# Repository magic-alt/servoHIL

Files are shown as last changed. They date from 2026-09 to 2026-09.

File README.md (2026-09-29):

# ServoHIL

**基于 Zynq UltraScale+ MPSoC 的单 SoC 实时伺服 Hardware-in-the-Loop 平台。**

ServoHIL 面向伺服驱动器、机器人关节模组与电机控制器的实时 HIL 验证。
当前活动硬件为 **Rev.B + ALINX AXU2CGB / ZU2CG**：ZU2CG 同时运行 Plant 与实时 I/O，
自研扩展板负责模拟量、PWM、编码器、RS-485、电源和独立硬件监督，不再增加第二颗 FPGA。

> **当前工程状态**
>
> - Schematic / source-level Layout entry：**已闭合**
> - PCB Layout：**允许开始**
> - Fabrication：**未放行**
> - Product / release qualification：**未放行**
>
> 机器契约：`layout_allowed=true`、`fabrication_allowed=false`、`release_allowed=false`。

---

## 1. Rev.B HIL 板架构

```text
                         ┌─────────────────────────────────────────────┐
                         │          ALINX AXU2CGB / ZU2CG            │
                         │                                             │
 Host / Test Software ──►│  PS/Linux        PL Real-Time Fabric       │
                         │                  ┌───────────────────────┐  │
                         │                  │ PMSM / mechanics Plant│  │
                         │                  │ stimulus / capture    │  │
                         │                  │ protocol engines      │  │
                         │                  │ health / lease logic  │  │
                         │                  └───────────┬───────────┘  │
                         └──────────────────────────────┼──────────────┘
                                                        │
                              J12 / 1.8 V                │ J15 / 3.3 V
                DAC + ADC high-speed digital             │ PWM / encoder / RS485 /
                                                        │ AUX / safety handshake
                                                        ▼
┌───────────────────────────────────────────────────────────────────────────────┐
│                         ServoHIL Rev.B Expansion Board                        │
│                                                                               │
│  9–15 V SELV                                                                 │
│      │                                                                        │
│      ▼                                                                        │
│  Fuse / reverse / TVS / TPS259474L eFuse                                     │
│      │                                                                        │
│      ├──► AP63201 ─► 6V2_PRE ─► LT3045 ─► +5V0_DAC                          │
│      │                         └► LT3045 ─► +5V2_PVDD                         │
│      ├──► AP63201 ─► 3V3_D                                                   │
│      ├──► AP63201 ─► 1V8_D                                                   │
│      └──► LT8330 ─► -6V2_PRE ─► LT3094 ─► -5V2_PVSS                         │
│                                  ADR4525 ─► VREF_2V5                          │
│                                                                               │
│  Analog Output                                                               │
│  ZU2CG ─► 4 × AD3542R ─► 8 × AO ─► 2 × ADG5412F ─► J5 ─► DUT              │
│                                                                               │
│  Analog Input                                                                │
│  DUT ─► J801 ─► protection + RC ─► AD7606C-16 ─► 8-lane serial ─► ZU2CG   │
│                                                                               │
│  Digital / Encoder                                                           │
│  DUT PWM ─► protection/buffer ───────────────────────────────────► ZU2CG     │
│  SSI/BiSS ⇄ THVD1450 PHY ⇄───────────────────────────────────────► ZU2CG     │
│  RS-485  ⇄ THVD1450 PHY ⇄───────────────────────────────────────► ZU2CG     │
│                                                                               │
│  Independent Supervision                                                     │
│  rail monitors + progress-qualified heartbeat + TPS3430 watchdog             │
│                  │                                                            │
│                  ├──► DAC reset / AO disconnect                              │
│                  ├──► HIL_FAULT_N / re-arm                                   │
│                  └──► AQY212GS floating DUT permit                           │
└───────────────────────────────────────────────────────────────────────────────┘
```

Rev.B 的核心目标不是做一块通用 DAQ，而是把
**`Plant → deterministic I/O → DUT → measurement → Plant`**
闭环所需的实时模拟/数字接口收敛到一块 ZU2CG 扩展板上，并对失效状态采用
fail-closed 的硬件边界。

---

## 2. 主要 I/O 能力

| 功能 | Rev.B 实现 | 备注 |
|---|---|---|
| Analog Output | 8 路，4 × AD3542RBCPZ16 | 16-bit DAC；经 ADG5412F 实现物理高阻断开 |
| Analog Input | 8 路，AD7606C-16BSTZ | 低能量实验室 ±10 V 前端候选；8-lane serial |
| PWM Capture | 6 路 | 3.3 V logic，SN74LVC541A 缓冲 |
| Encoder | 2 端口 SSI/BiSS-C | 每端口 CLK/DATA 两个差分对，THVD1450 |
| RS-485 | 1 路 | THVD1450，120 Ω 跳线终端 |
| AUX GPIO | 6 路 | 3.3 V logic |
| Management | I²C | 3.3 V |
| HIL handshake | HIL_ARM / HIL_WDI / HIL_FAULT_N | 与独立硬件 watchdog/supervision 配合 |
| DUT permit | 1 路 floating NO contact | AQY212GS；实验室非安全许可触点 |

当前扩展板**没有**板载 EtherCAT/CAN 控制器或 PHY；工业总线主站/协议验证属于其他
host/平台工作流，不应把 AUX 引脚描述成已实现 EtherCAT/CAN。

---

## 3. AXU2CGB / ZU2CG 接口

Rev.B 直接使用 AXU2CGB 的 J12/J15 扩展接口。

### J12 — 1.8 V GPIO domain

主要承载高速 ADC/DAC 数字接口：

- DAC：`SCLK`、`LDAC_N`、4 × `CS_N`、8 × `SDIO`、4 × `ALERT_N`
- ADC：8 × `DOUT`、`SCLK`、`CS_N`、`SDI`、`CONVST`、`BUSY`、`RESET`

### J15 — 3.3 V GPIO domain

主要承载外部数字/PHY 与硬件监督：

- 6 × PWM
- 2 × SSI/BiSS encoder ports
- 6 × AUX GPIO
- RS-485 TX/RX/DE
- I²C
- `HIL_ARM` / `HIL_WDI` / `HIL_FAULT_N`

完整逻辑映射见：

- `hardware/carriers/axu2cgb/physical_pinout.csv`
- `hardware/carriers/axu2cgb/assignments.csv`
- `hardware/revB/io_contract.json`

官方 ALINX DXF 已绑定：

- AXU2CGB outline：**100 × 85 mm**
- 4 个主安装孔及孔径
- J12/J15 2×20 / 2.54 mm pin grid
- J12/J15 几何中心
- 两个连接器的 pin-1 方向

仍未冻结：**AXU2CGB host connector MPN、mating connector MPN、mated stack height 和
carrier height keepout**。因此在这些机械事实闭合前，不使用通用 2×20 footprint
伪造可制造的 mating PCB。

---

## 4. 电源与模拟架构

Rev.B 接受 **9–15 V regulated SELV**，不是电机 48/67 V DC bus 输入。

### 输入保护

```text
J101
  │
  ▼
F101 2 A
  │
SS34 reverse-polarity protection
  │
SMBJ16A TVS
  │
TPS259474L eFuse
  │
VIN_PROT
```

关键设计计算：

- eFuse current limit：约 **1.51 A**
- UV：约 **7.95 V**
- OV：约 **15.91 V**

### 正电源

三路 AP63201：

| Rail | Nominal |
|---|---:|
| `6V2_PRE` | 6.184 V |
| `3V3_D` | 3.296 V |
| `1V8_D` | 1.792 V |

`6V2_PRE` 再经两路 LT3045 生成：

- `+5V0_DAC`
- `+5V2_PVDD`

### 负电源与参考

- LT8330 Cuk/inverting preregulator：约 `-6.24 V`
- LT3094：`-5V2_PVSS`
- ADR4525：`VREF_2V5`

当前 EDV 仍保留 DAC supply-span/headroom corner 问题；Layout 可以继续，
但 rail tolerance、DAC stability、MLCC derating、磁性损耗和实板 thermal
仍属于 fabrication/release gate。

详细计算：

- `docs/design/native-power-stage-calculations.md`
- `docs/design/native-power-supervision.md`
- `sim/power/README.md`

---

## 5. 硬件监督与失效语义

Rev.B 的 safety/interlock 设计原则是：

**软件/RTL 停止正常推进时，硬件必须能够独立撤销输出许可。**

主要链路包括：

- TPS3808 rail supervisors
- negative-rail comparator
- explicit arm / re-arm latch
- progress-qualified `HIL_WDI`
- TPS3430 window watchdog
- DAC hardware reset
- 2 × ADG5412F AO disconnect
- AQY212GS floating normally-open DUT permit

`health_heartbeat.sv` 不使用无条件 free-running heartbeat。
只有 Plant/I/O 完成序号持续推进并且 host lease 有效时才继续输出 WDI；
progress timeout、lease expiry、序号异常或显式 fault 都会撤销健康状态。

### 安全边界

以下语义必须保持明确：

- **AO disconnect = high impedance，不等于 guaranteed 0 V。**
- **J701 floating DUT permit 不是 STO。**
- J501/J701 为两线 contact 语义，跨线短路可能等效于“触点闭合”，因此
  **不是 cable-short fail-safe 或 redundant functional-safety channel**。
- Rev.B 当前定位为工程/实验室 HIL，不声明 IEC 功能安全认证。

---

## 6. 当前 Rev.B 工程状态

### 已完成

- 15 页原生 KiCad schematic topology
- 439 个 on-board physical instances
- 431 populated + 8 DNP
- native on-board blank footprint：**0**
- U20–U23 AD3542R exact CP-28-15 land pattern
- J101 / SW101 / J5 / J501 / J701 board-side exact part/footprint binding
- C105 TDK exact land pattern
- AD7606C-16 schematic + RTL initialization / eight-DOUT capture path
- PWM / SSI-BiSS / RS-485 / AUX electrical boundaries
- input/output connector protection topology
- progress-qualified heartbeat / watchdog integration framework
- source-bound electrical calculations and ngspice regression
- AXU2CGB official DXF mechanical baseline
- Rev.B complete costed BOM
- Layout-entry machine contract

### 当前 gate

| Gate | State |
|---|---|
| Schematic source closure | ✅ closed |
| Layout entry | ✅ `READY_FOR_PCB_LAYOUT` |
| PCB Layout | 🟡 active / next engineering phase |
| Fabrication | ❌ blocked |
| Product release | ❌ blocked |

机器状态源：

`hardware/revB/gates.json`

当前明确：

```text
layout_allowed      = true
fabrication_allowed = false
release_allowed     = false
```

---

## 7. PCB Layout 基线

Rev.B 目标为 **6-layer PCB**：

| Layer | Role |
|---|---|
| L1 | components + signals |
| L2 | continuous GND reference |
| L3 | power distribution + slow signals |
| L4 | signals |
| L5 | continuous GND reference |
| L6 | components + signals |

设计原则：

- 不硬切 AGND/DGND；使用连续 reference planes + functional zoning
- switcher hot loop 与 ADC/DAC/reference 空间隔离
- 高速/精密信号不得跨 reference-plane void
- 每次高速换层附近设置 GND stitching via
- ESD/TVS 紧邻 connector，回流路径最短
- ADC/DAC digital bus 保持短、少 stub、少 layer transition
- 120 Ω differential 目前是目标阻抗，不在厂商 stackup 前冻结 width/gap

Layout 顺序：

```text
mechanical reference / board outline / connector keepout
    ↓
stackup + design rules
    ↓
power + precision analog placement
    ↓
ground / return-path review
    ↓
routing
    ↓
PCB DRC
```

详细 contract：

- `hardware/revB/pcb_layout_contract.json`
- `hardware/revB/pcb_design_rules.json`
- `docs/review/revb-layout/README.md`

---

## 8. 完整 BOM 与当前成本

Rev.B costed BOM 由原生 KiCad 反向审计，不再依赖手工简化表。

`bom/revb-costed.csv`：

- **439** 个 on-board physical refs
- **431** populated
- **8** DNP
- **139** grouped procurement lines

2026-09-29 engineering planning snapshot：

| Build | Component cost |
|---|---:|
| 1 × fully populated Rev.B | **约 ¥4,085.41** |
| 5 × fully populated Rev.B | **约 ¥17,153.21** |
| 5-board average | **约 ¥3,430.64 / board** |

以上不含：

- bare PCB
- stencil
- SMT/THT assembly
- freight / VAT / duties
- AXU2CGB
- J12/J15 mating connector stack
- rework / yield reserve

4 × AD3542R 是主要成本来源；与 AD7606C-16 合计约占单板元器件预算的
**68%** 左右，因此首板更适合采用“多做裸板、少量全贴”的 staged population。

采购状态区分：

- `EXACT_QUOTE`
- `EXACT_MPN_NO_LIVE_QUOTE`
- `CANDIDATE_QUOTE`
- `ORDERABLE_MPN_MISMATCH`
- `BUDGET_GENERIC`
- `DNP`

当前 U501 仍显式标记采购异常：
schematic 为 `TPS3430DRCR`，当前 active orderable candidate 为
`TPS3430WDRCR`；fabrication 前必须完成 variant/package/timing 审查并统一 schematic/BOM，
不能静默替换。

详细成本与采购策略：

- `bom/revb-costed.csv`
- `bom/revb-cost-summary.json`
- `bom/revb-pricing-sources.csv`
- `docs/design/revb-procurement-and-cost.md`

---

## 9. 设计文档入口

第一次接手 Rev.B，建议按以下顺序阅读：

1. **本 README** — 系统架构、工程状态和路线图
2. **`docs/design/revb-hardware-design-guide.md`** — 单一完整硬件设计说明书
3. **`hardware/carriers/axu2cgb/assignments.csv`** — ZU2CG ↔ Rev.B 信号映射
4. **`hardware/revB/io_contract.json`** — I/O 电气与逻辑契约
5. **`hardware/revB/pcb_layout_contract.json`** — PCB Layout 边界
6. **`docs/review/revb-layout/README.md`** — Layout placement/routing 规则
7. **`docs/review/revb-peripherals/README.md`** — ADC / PHY
8. **`docs/review/revb-safety/README.md`** — watchdog / interlock / DUT permit
9. **`sim/power/README.md`** — EDV / ngspice
10. **`docs/design/revb-procurement-and-cost.md`** — BOM / cost / sourcing

活动 KiCad 工程：

```text
hardware/kicad/revB/axu2cgb_expansion/servohil_io_revB.kicad_pro
```

原生 `.kicad_sch/.kicad_sym/.kicad_pro` 是设计源。
历史 review PDF、早期 XML 和 Rev.A snapshot 仅作为历史证据，不覆盖当前 native source。

---

## 10. Repository layout

```text
servoHIL/
├─ hardware/
│  ├─ kicad/revB/axu2cgb_expansion/   # active native Rev.B schematic / PCB source
│  ├─ revB/                            # machine-readable design/release contracts
│  └─ carriers/axu2cgb/               # carrier pinout / assignments / mechanics
├─ rtl/revb/                           # ADC / health / runtime integration RTL
├─ sim/
│  ├─ power/                           # analytical + ngspice EDV
│  └─ peripherals/                     # load / ADC frontend screening
├─ bom/                                # complete costed BOM + source ledger
├─ docs/design/                        # consolidated engineering design docs
├─ docs/review/                        # review checkpoints / evidence notes
├─ tests/                              # source / mutation / contract regressions
├─ tools/                              # repository / schematic / BOM / qualification checkers
└─ archive/revA/                       # superseded dual-FPGA historical design
```

---

## 11. 本地验证

推荐环境：

- Python 3.11+
- KiCad CLI
- ngspice
- Icarus Verilog

核心 source/contract 检查：

```sh
python tools/check_revb_schematic_closure.py
python tools/check_revb_prelayout_contract.py
python tools/check_revb_pcb_layout_contract.py
python tools/check_revb_costed_bom.py
python tools/revb_qualification.py
python -m unittest discover -s tests -v
```

原生 KiCad/ERC 路径：

```sh
mkdir -p build/native

kicad-cli sch export netlist \
  --format kicadxml \
  -o build/native/netlist.xml \
  hardware/kicad/revB/axu2cgb_expansion/servohil_io_revB.kicad_sch

python tools/check_native_readability.py \
  --normalize build/native/netlist.xml \
  --output build/native/canonical.xml

python tools/verify_native_all.py build/native/canonical.xml --stage supervision
python tools/check_revb_netlist.py \
  build/native/canonical.xml \
  hardware/kicad/revB/axu2cgb_expansion/expected_connections.json

python tools/check_native_safety.py build/native/canonical.xml

kicad-cli sch erc \
  --format json \
  --exit-code-violations \
  -o build/native/erc.json \
  hardware/kicad/revB/axu2cgb_expansion/servohil_io_revB.kicad_sch

python tools/check_revb_erc.py build/native/erc.json
```

CI 的 skipped 项只有在明确缺少对应 native tool/evidence 时才可接受；
**自动化通过不等于 electrical qualification 或 fabrication release。**

---

## 12. Pre-Layout 成本 / 架构决策

在冻结 DAC、电源和 precision-analog placement 之前，项目增加一个个人版成本决策门：

- 不再把 **8 路 AD3542R-16 全装**视为首板默认配置；
- 当前推荐 baseline 为 **4 路 fast AO，可扩展到 8 路**；
- 优先验证 AD3542R-12 是否已满足实际 DUT 分辨率；
- AD7606C-16 可在首个闭环样机中作为可选 DNP；
- 必须先实测 `PWM capture -> Plant -> AO settled -> DUT ADC sample` 的真实时序余量；
- 如果余量 >10 us，才值得进一步切换 DAC80504 / DAC81404 一类低成本 DAC；
- 如果余量 <2 us，则继续保留 AD3542R fast-precision 路线。

完整决策、替代器件、成本和实施收益见：

`docs/design/revb-prelayout-cost-feasibility-decision.md`

该决策不改变机器 gate：`layout_allowed=true` 仍表示可以继续机械/板框/规则工作；
但 **DAC / analog power / precision placement 不应冻结**，直到 fast-AO 数量、有效分辨率
和 DUT ADC timing margin 三项实测闭合。

---

## 13. 下一阶段

原理图已经不再是主要工作面。当前工程优先级是：

1. **绑定 J12/J15 exact host/mating connector、stack height 与 height keepout**
2. 创建活动 `.kicad_pcb`
3. 冻结 board outline / mounting holes / connector placement / keepout
4. 绑定 PCB 厂 6-layer stackup 和真实 impedance geometry
5. power / precision-analog critical placement
6. grounding / return path review
7. routing
8. PCB DRC
9. fabrication qualification
10. 首板 bring-up + thermal / backfeed / fault injection / EMC
11. Vivado functional I/O DRC + STA/CDC
12. DUT adapter qualification
13. FOC physical closed-loop HIL acceptance

仍然阻塞 fabrication/release 的主要证据包括：

- exact J12/J15 connector stack
- MLCC DC-bias / temperature / aging / ESR / RMS
- XAL L(I,T) / AC / core / winding loss / saturation
- real DUT thresholds / leakage / cable-fault / shutdown time
- partial-power / backfeed
- mounted-board thermal
- low-energy fault-injection fixture
- Vivado raw I/O DRC + functional STA/CDC
- EMC / power-down / physical fault injection
- FOC closed-loop acceptance

---

## 14. Release philosophy

ServoHIL Rev.B 使用显式、fail-closed 的工程门禁：

- footprint 正确 ≠ electrical qualification
- ERC / DRC 通过 ≠ fabrication approval
- ngspice PASS ≠ mounted-board thermal PASS
- watchdog/interlock 电路存在 ≠ certified functional safety
- catalog rating ≠ real DUT compatibility
- prototype works ≠ release qualification

**只有与准确 source revision、实际硬件、实际 DUT 和原始测试 evidence 绑定的结果，
才允许关闭对应 release gate。**

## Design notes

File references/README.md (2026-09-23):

# Design references

Use vendor-primary documents for electrical freeze decisions.

## ADI

- AD3542R: https://www.analog.com/en/products/ad3542r.html
- EVAL-AD3542R: https://www.analog.com/en/resources/evaluation-hardware-and-software/evaluation-boards-kits/eval-ad3542r.html
- ADR4525: https://www.analog.com/en/products/adr4525.html
- ADP5054: https://www.analog.com/en/products/adp5054.html
- ADM1186: https://www.analog.com/en/products/adm1186.html
- LT3045: https://www.analog.com/en/products/lt3045.html
- LT3094: https://www.analog.com/en/products/lt3094.html
- LTC7149: https://www.analog.com/en/products/ltc7149.html

## AMD / Xilinx

- AMD 7 Series overview: https://docs.amd.com/v/u/en-US/ds180_7Series_Overview
- Artix-7 family: https://www.amd.com/en/products/adaptive-socs-and-fpgas/fpga/artix-7.html

## ALINX

- AXU2CGB product: https://www.en.alinx.com/Product/SoC-Development-Boards/Zynq-UltraScale-plus-MPSoC/AXU2CGB.html

Retain local vendor documents only when redistribution permits. Otherwise record the canonical URL and document revision/date.

Before freezing any resistor, capacitor, compensation, feedback or FPGA package-pin value, check the current vendor document and record the review source in the schematic or design note.

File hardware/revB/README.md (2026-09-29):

# Rev.B hardware contract and release boundary

Rev.B is a **single-ZU2CG** HIL architecture. The active editable native KiCad source is:

```text
hardware/kicad/revB/axu2cgb_expansion/servohil_io_revB.kicad_pro
```

For the consolidated design rationale, calculations, pin definitions, Layout
rules, procurement policy and first-board bring-up procedure, use:

- `docs/design/revb-hardware-design-guide.md`
- `docs/design/revb-procurement-and-cost.md`
- `bom/revb-costed.csv`

## Current gate state

The 15-page source-level schematic and Layout-entry contract are closed sufficiently
to start PCB placement/routing:

- `layout_allowed=true`
- `fabrication_allowed=false`
- `release_allowed=false`
- layout-entry status: `READY_FOR_PCB_LAYOUT`

This means **Layout may proceed, but Gerber/fabrication/production release may not**.

The five previously open board-side mechanical parts are now source-bound for
Layout: J101=Phoenix 1757242, SW101=PTS645SM43SMTR92 LFS,
J5=Phoenix 1844294, J501=Phoenix 1844210 and J701=Molex 43045-0212.
C105 is bound to TDK C5750X7R1V476M230KC and U20..U23 retain the reviewed exact
AD3542R CP-28-15 land pattern. The current native source audit has **zero on-board
blank footprints**.

AXU2CGB official CAD now binds the 100 x 85 mm host outline, four mounting holes,
J12/J15 pin grids/centers and pin-1 orientation. Exact host/mating connector MPN,
mated stack height and carrier component-height keepouts remain open, so a guessed
generic 2x20 mating footprint must not be released.

## Qualification boundary

The following remain fabrication/release gates:

- exact J12/J15 host/mating connector stack definition;
- manufacturer MLCC and magnetic characterization;
- power margin and DAC analog stability;
- real DUT adapter neutral/permit thresholds, leakage, cable-fault behavior and
  maximum shutdown time;
- partial-power/backfeed and powered-off interface behavior;
- assembled-board thermal;
- low-energy fault-injection fixture;
- Vivado raw I/O DRC and functional STA/CDC bound to the exact part/top/XDC/source;
- EMC, power-down, physical fault injection and FOC closed-loop acceptance.

J501/J701 remain laboratory non-safety dry-contact/permit interfaces. A cross-line
cable short can mimic a closed contact; neither interface is STO or redundant
functional safety.

## Costed BOM contract

`bom/revb-costed.csv` covers all **439** on-board physical refs:
**431 populated + 8 DNP**, grouped into **139 purchasing lines**.
`tools/check_revb_costed_bom.py` fails if coverage drifts.

The 2026-09-29 planning snapshot is approximately **CNY 4,085.41** components for
one fully stuffed board and **CNY 17,153.21** components for five fully stuffed
boards after applicable small-quantity breaks. These figures exclude PCB,
assembly, freight/tax, AXU2CGB and the still-unbound J12/J15 mating connector stack.

The BOM also records U501 as an explicit `ORDERABLE_MPN_MISMATCH`: schematic
`TPS3430DRCR` versus TI's current active orderable `TPS3430WDRCR`. It must be
resolved by design review before fabrication, not silently substituted.

## Checks

```sh
python tools/check_revb_schematic_closure.py
python tools/check_revb_prelayout_contract.py
python tools/check_revb_pcb_layout_contract.py
python tools/check_revb_costed_bom.py
python tools/revb_qualification.py
```

Passing these source/contract checks is not a physical qualification or production
certificate.

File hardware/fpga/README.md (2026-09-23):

# Local I/O FPGA hardware contract

Candidate device: `XC7A35T-1FGG484I`.

The Local FPGA is a deterministic I/O engine, not the plant solver.

Responsibilities:

- HIL-Link endpoint,
- edge/event timestamping,
- frame CRC and FIFO,
- AD3542R serialization and LDAC scheduling,
- autonomous watchdog/safe-state generation,
- future ADC/DIO/encoder PHY glue.

The Rev.A FPGA source-of-truth is under `hardware/fpga/revA/`.

Concrete PACKAGE_PIN constraints must originate from Vivado I/O Planner and then be cross-checked against the KiCad schematic. No BGA ball assignment is to be invented in documentation first.

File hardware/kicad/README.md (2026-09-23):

# KiCad hardware development rules

The native Rev.A project lives in `hardware/kicad/revA/`.

Rev.A is currently in the **schematic phase**. The machine-readable layout authority is `hardware/kicad/revA/layout_gate.yaml`.

## Sheet ownership

- 01_POWER_ENTRY
- 02_ANALOG_POWER
- 03_DIGITAL_POWER
- 04_AXU_HIL_LINK
- 05_IO_FPGA
- 06_DAC_0_3
- 07_DAC_4_7

Future ADC/DIO/Encoder/CAN/RS485/FIU sheets remain deferred.

## Rules

- Do not guess regulator magnetics/compensation.
- Do not guess XC7A35T BGA balls directly in KiCad.
- Treat `docs/icd/j12-hil-link.csv` as the J12 mapping authority.
- Treat Vivado I/O Planner/XDC as the FPGA pin-placement authority.
- Treat KiCad ERC plus schematic review as mandatory before layout.
- Generated fabrication output is not source-of-truth.

## Before layout

All entries in `layout_gate.yaml` must pass in a reviewed commit. CI intentionally blocks premature PCB layout.

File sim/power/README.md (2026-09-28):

# Rev.B Electrical Design Verification

**Engineering screening, NOT layout or purchase approval.** Native KiCad remains
unchanged. In particular, the currently requested +/-5 V output and the +/-5.2 V
rail tolerance/headroom conflict are not fixed by a successful simulator job.

## Reproduce

Use Python 3.11+ and ngspice on PATH, in a clean checkout of the PR branch.
The CI records the actual simulator version and executable SHA256. Linux CI uses
ngspice-42 at the reviewed checkpoint; do not assume another simulator version
has identical solver behavior. For tests only, `NGSPICE` may name an executable.
The `spice.py` command resolves `ngspice` from PATH.

```sh
python -m unittest discover -s tests -p 'test_edv*.py' -v
python sim/power/analysis.py --output build/edv/analysis
python sim/power/qualification.py --output build/edv/components
python sim/power/capacitors.py --output build/edv/capacitors
python sim/power/spice.py --output build/edv/run-001
python sim/power/evidence.py build/edv/run-001 --expected-source-commit "$(git rev-parse HEAD)"
python sim/power/analysis.py --strict-design --output build/edv/analysis
```

The final command must currently exit **2**, because design blockers exist.
Other commands exiting zero mean the calculation/execution/integrity work ran;
they do not clear `hardware/revB/gates.json`. On PowerShell, inspect
`$LASTEXITCODE` after the strict command. Never run all commands under an
unconditional `|| true` that hides simulation failures.

Every executed SPICE run requires a **new output directory**. Existing output is
refused, including a previous successful run. Keep failed runs for diagnosis;
choose `run-002` instead of overwriting evidence. A failure leaves a `FAILED`
manifest with the completed case count and original logs. A process killed
without cleanup may leave `RUNNING`; neither status passes `evidence.py`.

For one-case debugging use `--case buck_6V2_PRE_8V`. This produces a valid
single-case execution, but intentionally fails the **full-matrix** integrity
gate. `--emit-only` creates portable `.cir` decks and prints `EMITTED_NOT_RUN`.

## What the models cover

| Layer | Current implementation | What it cannot establish |
|---|---|---|
| Analytical | Native R/L/C values; FB and SET corners; 162 Cuk sensitivity points; thermal envelopes; nine capacitor banks | Dynamic stability, actual temperature, lifetime/production qualification |
| Switched power network | 12 buck + 4 Cuk cases; input ramps, half-to-full **resistive** load steps, switching-disable discharge | AP63201/LT8330 compensation, IC soft-start, Burst Mode, short-circuit/current limit or hiccup |
| LDO envelope | Nine SET-current/RSET corners; native CSET and Cout; assumed gm, fast-start, dropout and current ceiling | LT3045/LT3094 loop stability, PSRR, noise, thermal shutdown, reverse current, real PG timing |
| Vendor preparation | Exact LT3045/LT3094/LT8330 `.asy`/`.SUBCKT` pin-order binding and deck/model hashes | No manufacturer macro-model simulation has been executed here |
| Physical bench | No new board measurements | No hardware PASS |

The power topologies are explicit hand-authored bench networks with native-value
binding, not an automatic SPICE export of every KiCad wire or parasitic. A
native topology change requires reviewing the bench network as well as rerunning
the digest/connection checks; the source hash alone cannot prove physical fidelity.

`startup_s` is the first 90% crossing in the **imposed stimulus**, not a guaranteed
IC startup or monotonic-settling specification. `shutdown_v` is measured at
99.9% of the finite simulation end time, not an acceptance of safe discharge.
Buck/Cuk shutdown removes gate drive while holding the bus; LDO shutdown ramps
the input down. These are different cases, not a common system power-off test.
No AC loop-gain/phase-margin sweep is claimed.

The switched clock uses finite rise/fall of `T/100` and width `D*T - edge` to
preserve its integrated duty. The original 1 ns edge gave D=0.7744167 rather than
0.773 on ngspice-42. The original 0.001 duty-error gate remains unchanged, and a
real-simulator half-max-timestep regression checks mean/peak convergence.

### Cuk model applicability

For the uncoupled-inductor approximation, check the valley of the **sum** of the
currents flowing through the diode/switch. An individual inductor current
reversing is not, by itself, the diode discontinuous-mode criterion. Ninety-nine
of the 162 current analytical sensitivity points fail the positive-sum valley
check. Their CCM arithmetic remains visible for diagnosis, **not as a guaranteed
peak/RMS bound**. Exact feedback limits include the LT8330 Rev D p3 negative-FBX
range, pin-bias current and line regulation; `assumptions.json` records the source.

All four imposed-duty Cuk cases are outside the 5% mean-output screen. Retain
those results: do not adjust duty merely to turn the report green. Actual
closed-loop regulation/current stress still needs the correct manufacturer
model and independent bench evidence, including light-load mode.

## Exact components and MLCC curves

`component_candidates.json` binds five magnetic references to catalog candidates:
L201/L301/L302 XAL5050-103MEC, L202 XAL5050-682MEC and L203 XAL5030-472MEC.
Catalog typical Isat at 30% inductance drop and catalog temperature-rise current
are not guaranteed current limits on this PCB. Close L(I,T), high-frequency core
and winding loss, startup/fault current, footprint/height and actual temperature
before freezing parts. Cuk candidate rows expose the invalid-CCM screening status.

`capacitor_candidates.json` is a **candidate** catalog, not a BOM edit:

| Native bank | Candidate | Recorded caveat |
|---|---|---|
| Six 2x22 uF banks | TDK C3225X7R1C226M250AC, 16 V X7R 1210 | Production catalog part is **+/-20%**, max height 2.8 mm; do not apply generic +/-10% tolerance |
| C414/C415 | TDK C3225X7R1E106K250AC, 10 uF 25 V X7R 1210 | Higher voltage rating is not proof of interchangeability; effective-capacitance target still open |
| C410 | TDK CGA6L2X7R1H105K160AA, 1 uF 50 V X7R 1210 | Production automotive AEC-Q200 candidate; DC-bias, RMS-current/ESR and effective-C qualification remain open |
| C105 | TDK C5750X7R1V476M230KC, 47 uF 35 V X7R 2220 | Production exact-MPN screening candidate; native C105 now binds X7R, but the generic KiCad 2220 footprint still requires TDK exact land-pattern/height review; >=22 uF effective at 15.05 V still requires hash-bound DC-bias data plus temperature/aging and RMS/ESR review |

Exact manufacturer source discovery is now also centralized in
`hardware/revB/component_evidence_sources.json`. The Coilcraft XAL50xx document
and exact TDK characterization-sheet URLs are recorded there, with status explicitly
kept as source-located/not-hash-imported. Do not convert those URLs or transcribed
catalog values into a curve PASS. Archive the actual reviewed source bytes and
SHA-256, record test/graph conditions, then import reviewer-controlled normalized
data without extrapolation.

Manufacturer source URLs, lifecycle check date and height are in the catalog.
Every reference's native capacitance, case and minimum voltage rating is checked.
Changing the second parallel capacitor cannot silently reuse a stale candidate.
The catalog-specific report takes precedence over `analysis.py`'s explicitly
named generic 10%-tolerance sensitivity. With the 20%-tolerance 22 uF candidate,
20 uF effective requires at least 68.91% bias retention under the assumed 15%
temperature and 3% aging losses. That is a **requirement**, not imported data.
The 3% aging and 50 mV voltage reserve are still engineering assumptions.

### Coilcraft XAL L-vs-current evidence import

XAL L-vs-current evidence uses the same fail-closed pattern as MLCC curves. The
checked-in report without a curve pack remains `BLOCKED_MISSING_CURVE`:

```sh
python sim/power/magnetics.py --output build/edv/magnetics
```

After an engineer obtains the reviewed Coilcraft source bytes, create one pack
per exact MPN (`XAL5050-103MEC.json`, `XAL5050-682MEC.json`,
`XAL5030-472MEC.json`) with:

- `schema: 1`, `manufacturer: "Coilcraft"`, exact `part_number`;
- `characteristic: "L_VS_CURRENT_REFERENCE"`;
- the reviewed HTTPS `source_url`, retrieval date, reviewer and normalization note;
- conditions including `temperature_c` and a nonempty `curve_basis`;
- an `original` file + SHA-256 and reviewer-normalized CSV + SHA-256.

The normalized CSV columns are exactly `current_a,inductance_uh`, begin at 0 A,
remain strictly increasing in current, and are never extrapolated.

```sh
python sim/power/magnetics.py \
  --curve-dir /path/to/reviewed-xal-packs \
  --output build/edv/magnetics-with-curves
```

Even a byte-valid exact-MPN curve can only produce
`SCREEN_ONLY_REFERENCE_CURVE`; Coilcraft L(I) graphs are treated as
typical/reference evidence. AC/core+winding loss, startup/short saturation and
mounted-board thermal evidence remain separate blockers.

No actual manufacturer curve CSV has been imported. To import reviewed evidence:

```sh
python sim/power/capacitors.py --curve-dir /path/to/reviewed-packs --output build/edv/capacitors-with-curves
```

For each MPN, provide `<MPN>.json` containing `schema: 1`, exact `part_number`,
HTTPS `source_url`, ISO `retrieved_on`, named `reviewer`, `normalization_note`,
and `conditions` with `temperature_c`, `ac_voltage_rms_v`, `frequency_hz`.
Both `original` and `normalized_csv` records must contain a relative `file` path
and the actual lowercase SHA256. Retain the original vendor export or source
snapshot and the reviewer-controlled normalized CSV together in the pack.
CSV columns are exactly `voltage_v,retention`; normalize to 1 at 0 V, retain
strictly increasing voltage and finite positive fractions <=1. No extrapolation.
The importer calculates from the **hashed CSV bytes**, never optional JSON
`points`. Traversal, escaping symlinks, wrong MPN, missing conditions and hash
mismatch are rejected. Test fixtures are explicitly SYNTHETIC and are not vendor
curves. Hash matching proves byte identity, not source authenticity. Reference
curves at one temperature do not establish simultaneous bias/temperature or
lifetime bounds, and even a successful screen stays `NOT_QUALIFIED`.

## Manufacturer LTspice workflow

Obtain the exact device symbol and matching readable library from an authorized
ADI/LTspice installation or official device page, subject to its license. Do not
commit or publish vendor IP in this repo or generic CI artifacts. For example:

```sh
python sim/power/vendor_ltspice.py --device LT3045 --rail 5v2 --symbol /vendor/LT3045.asy --model /vendor/LT3045.lib --output build/edv/vendor-lt3045
python sim/power/vendor_ltspice.py --device LT3094 --symbol /vendor/LT3094.asy --model /vendor/LT3094.lib --output build/edv/vendor-lt3094
python sim/power/vendor_ltspice.py --device LT8330 --symbol /vendor/LT8330.asy --model /vendor/LT8330.lib --output build/edv/vendor-lt8330
```

These paths are examples, not a claim that those files are installed. Pin order
comes from `SpiceOrder`, not package pin numbers. Missing/encrypted/incompatible
headers mean BLOCKED; use the official demo workflow rather than guessing pins.
Do not substitute LT3045-1 or AP63200 for LT3045 or AP63201.

After preparation, inspect model licensing, all `.include` dependencies, pin
mapping, convergence and the vendor model's supported behaviors. Run the clean
bench in the actual licensed LTspice environment, retaining tool/version,
model/dependency hashes, deck, raw measurements and all stepped conditions.
Verify output polarity and realistic startup, full load, release and shutdown.
Repeat with reviewed effective C/ESR/DCR and temperature/load corners. The
preparation report stays `PREPARED_NOT_RUN`; it is **not** a result importer.
AP63201 exact vendor-model availability/coverage remains open. The preparation
uses assumed diode/ESR/DCR and does not independently qualify those components.

## Evidence and release boundary

`evidence.py` requires all 25 current case IDs, a clean source identity, matching
source digest, 125 artifact hashes, native-bound deck hashes and raw-log/JSON
measurement/assessment consistency. It rejects stale source, subsets, duplicated
cases and incomplete output. This is integrity verification, not cryptographic
simulator attestation or a full waveform-physics validator. `--root` permits
verifying an archived run against its accompanying exact source snapshot; never
silently point an old report at new source.

GitHub PR workflows may execute a **merge-test SHA**, not the PR head SHA.
`source_commit.txt`, `source_tree.txt`, `source.zip`, `results.json` and the
integrity report record that distinction. Match native-source files before
reusing a KiCad netlist from another read-only CI job.

The closure sequence is: resolve DAC supply/headroom architecture; run correct
vendor closed-loop/mode models; archive real MLCC and magnetic curves; close
thermal and input-protection/backfeed stress; then independent hardware tests
and a separate layout-gate review. Do not expand ADC/PHY or start PCB layout
because Python tests or ngspice returned success. See
[review evidence and open findings](../../docs/review/revb-edv/README.md).

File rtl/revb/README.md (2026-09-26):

# Rev.B runtime health producer

`health_heartbeat.sv` is a synthesizable one-clock-domain core. It is not a board
bitstream, a Plant implementation, an AXI register file or a CDC bridge.

At **100 MHz**, default WDI falling edges are **5 ms** apart; each half-period is
2.5 ms. PLANT/IO deadlines are 100 us and host lease is 10 ms. These are explicit
engineering defaults, not proof that a particular Plant satisfies its deadlines.
Clock changes require re-deriving all parameters; never retain a 100 MHz parameter
set while using another clock. Cycle limits are integers >=2.

## Accepted transaction contract

All data/control inputs must be stable in `clk` domain. Assert reset asynchronously
if required and deassert synchronously upstream. A PS/AXI producer must transfer
sequence and valid atomically, with a proper CDC handshake if clocks differ.

`plant_valid/plant_seq` acknowledge a completed Plant step. `io_valid/io_seq`
acknowledge the completed required I/O set for a step, not merely a FIFO write,
DMA submission, DAC command request or timer interrupt. `lease_valid/lease_seq`
acknowledge a genuinely renewed host/session lease. An always-incrementing PL
counter is not an acceptable implementation of any of these sources.

The first sequence establishes the baseline. Subsequent accepted progress must
be exactly +1 modulo 2^32. An identical value is ignored and does not extend the
deadline; a jump/backward sequence faults. If a faster producer coalesces work,
place a reviewed per-accepted-transaction sequence adapter upstream; this core
does not treat arbitrary jumps as proof of progress.

A fault latches WDI at its present level and immediately withdraws `hil_arm` on
the detecting clock. There is no synthetic final falling edge. Later activity
cannot clear the fault. To start/recover, pulse `session_start` with ARM low and
runtime_fault absent; all three sources must then establish fresh progress. A
session-start during healthy tracking faults rather than refreshing deadlines.

`healthy` means *runtime sources fresh*, **not board RAILS_OK**. WDI runs while
disarmed so the external TPS3430/two-edge/TPS3808 chain can qualify. HIL_FAULT_N
is not a pre-arm heartbeat qualifier: the existing board asserts fault while
unarmed, and feeding that back would deadlock startup. `arm_request` must remain
low until the commissioning controller has allowed the hardware qualification
sequence; then issue a fresh rising edge. A premature attempt can be rejected by
the board ARM latch and requires explicit disarm/retry, not automatic toggling.
A future board integration must validate that sequence and monitor the actual
DUT permit/feedback. No RAILS_OK GPIO or host-health integration is invented here.

The core sees ARM low in a healthy session before permitting a rising edge.
ARM high through reset/recovery never arms. Dropping ARM disarms without stopping
an otherwise healthy heartbeat. The external safety chain remains authoritative;
this single-clock RTL is not redundant and does not establish STO/SIL/PL.

## Latched reason mask

| Bit | Meaning |
|---|---|
| 0 | Explicit runtime fault |
| 1 / 2 / 3 | Plant / I/O / lease deadline |
| 4 / 5 / 6 | Plant / I/O / lease sequence discontinuity |
| 7 | Invalid session start (live session, ARM high or runtime fault) |

Deadlines count clocks since the last accepted advance. Progress on the last
allowed clock refreshes the age; absent/duplicate input at that clock faults.
Faults take precedence over heartbeat toggles and ARM rises. Source counters and
latched failures cannot wrap to healthy after a long outage.

## Verification

`python -m unittest discover -s tests -p test_health_rtl.py -v` runs real Icarus
compilation and simulation. Small-cycle directed vectors cover missing/duplicate
progress, discontinuities, uint32 wrap, deadline boundaries, fault priority,
held-high ARM, deliberate recovery and healthy-disarmed feed. A second bench
runs default parameters for 11 ms at 100 MHz and checks the actual 5 ms falling
edge interval. Numerical simulation is not timing closure or hardware evidence.

Still required: reviewed PS/AXI/CDC session integration; actual Plant and I/O
completion producers; top-level/XDC binding; Vivado synthesis/STA/IO DRC; external
watchdog startup and fault injection; measured hardware disable/DUT reaction.

## AD7606C-16 digital initialization / acquisition core

`ad7606c16_controller.sv` implements only the reviewed digital transaction
boundary. After an explicit `start_init`, it pulses RESET, writes CONFIG
address 0x02 with 0x18 (eight DOUT lanes), issues a serial register-read command,
and requires the following DOUTA frame to read back 0x18 before `configured`
can assert. The all-zero readback frame returns the device to ADC mode.

A `sample_request` then produces CONVST, requires BUSY assertion and
deassertion within the configured timeout, clocks exactly 16 bits from all eight
DOUT lanes, and only then emits one-cycle `sample_valid` and increments
`sample_seq`. CONFIG mismatch or BUSY timeout is latched fail-closed until a
new explicit initialization.

The core follows the AD7606C-16 serial software-mode command framing, but it is
not a calibration, anti-alias, 1 MSPS, CDC, top-level pin or Vivado timing proof.
Those remain separate qualification gates.

## Runtime completion integration

`runtime_health_integration.sv` is the narrow accepted-event boundary feeding
`health_heartbeat`. It accepts only completed Plant sequence events, completed
ADC sample sequence events, and validated host-lease renewal sequence events.
Duplicate or gapped sequences retain the existing fail-closed health behavior.

AXI/CDC/top-level adapters are intentionally outside this module. They must
convert their domain-specific acknowledgements into one-cycle accepted events in
the reviewed health clock domain; merely submitting work is not evidence of
completion. This wrapper therefore closes the semantic wiring seam, not the
Vivado CDC/timing or software authentication qualification.

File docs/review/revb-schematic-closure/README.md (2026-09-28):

# Rev.B schematic closure

**Date:** 2026-09-28  
**Scope:** native KiCad source closure only; no PCB/Layout authorization.

## What is closed in source

The Rev.B root project contains **15 functional sheets** and 439 physical
`in_bom=yes && on_board=yes` instances by the source audit. Purchased AXU2CGB
J12/J15 interfaces are schematic boundaries, not expansion-board placements.

This closure includes:

- connector protection placed in the owning interface sheets (`03/06/50/70/80`) so page-local nets remain local;
- exact local package bindings where the reviewed manufacturer package has a matching
  project-local KiCad land pattern: LT3045/LT3094 MSOP-12+EP, TPS3430 DRC VSON,
  LVC1G74 DCT, AQY212GS SOP-4, Littelfuse 451 fuse, XAL5030 and the reviewed
  TPS259474 RPW/XAL5050 land-pattern bindings;
- exact AD3542RBCPZ16 CP-28-15 bindings on U20..U23 using a locally vendored
  footprint reconstructed and independently checked against the official
  EVAL-AD3542RFMCZ IPC-356/top-copper/solder-mask/paste evidence;
- a fail-closed package/BOM audit in `tools/check_revb_schematic_closure.py`;
- connector-side clamps for low-energy AI/AO, 3.3 V logic, SSI/BiSS, RS-485 and the
  dry-contact interlock;
- independent oracle assertions for the added protection-device pins and packages.

## Deliberate remaining physical bindings

The only blank physical footprints allowed are defined in
`hardware/revB/schematic_open_items.json`. At this checkpoint there are **5**,
all requiring the real mechanical/enclosure/cable/DUT contract:

- J101 — 12 V field connector;
- SW101 — power-reset switch;
- J5 — AO connector;
- J501 — 3.3 V dry-contact service connector;
- J701 — floating DUT-permit connector.

U20..U23 are no longer blank-footprint blockers. The AD3542R package review is
source-bound through:

- `hardware/revB/ad3542r_footprint_evidence.json`;
- `hardware/revB/evidence/ad3542r/u1_geometry_review.json`;
- `Package_DFN_QFN:AnalogDevices_CP-28-15_AD3542R`.

The official EVAL BOM binds U1 to AD3542RBCPZ16. The official IPC-356 contains
exactly pins 1..28, and the EVAL top copper/paste/mask data defines a 28-pad
perimeter land pattern at 0.40 mm pitch with **no center exposed pad**. The local
footprint reproduces those copper/paste dimensions and explicit mask apertures.
A generic nominal 4 mm QFN is still not an acceptable substitute.

U101 and L201/L202/L301/L302 are likewise no longer blank-footprint blockers.
Their package/land-pattern bindings are source-closed, but that **does not**
qualify the components electrically, thermally or mechanically for production.

L203 uses the exact official `Inductor_SMD:L_Coilcraft_XAL5030` footprint.
None of these footprint assignments establish L(I,T), AC/core loss, startup
saturation, board temperature rise, placement clearance or manufacturability.

## AD3542R package evidence boundary

The AD3542R package blocker is now closed at source level, not by package-name
guessing. The review pins the exact manufacturer artifact SHA-256 values and retains
the U1 IPC-356/Gerber geometry needed to reproduce the footprint.

This closure proves the checked-in U20..U23 land-pattern binding. It does **not**
qualify DAC accuracy, dynamic settling, output stability, thermal behavior, EMC,
fabrication process or the finished PCB.

## Protection boundary

The DUT-permit protection intentionally does not clamp the floating
`DUT_PERMIT_A/B` contact to board ground. Cross-line protection must be selected only
after the actual DUT voltage, leakage, cable and isolation requirements are bound.

All connector protection parts are source-level topology decisions. Physical
qualification still requires connector-entry placement review, short return paths,
partial-power/backfeed tests, cable/common-mode conditions, IEC ESD/surge testing and
raw evidence.

## Electrical qualification boundary

The XAL5050/XAL5030 candidate MPNs and their catalog Isat/Irms/DCR values are screening
inputs, not board qualification. The remaining magnetic gate requires, at minimum:

- supplier L-versus-DC-bias and temperature evidence;
- AC/core plus winding-loss evaluation at the actual switching waveforms;
- startup/short-circuit/current-limit saturation analysis;
- exact land-pattern/height/clearance verification;
- mounted-board temperature-rise evidence.

MLCC candidates similarly remain blocked on exact-MPN DC-bias evidence, aging,
temperature, RMS-current/ESR where applicable, and real load/startup transients.
Analytical EDV success must not be converted into a production PASS.

## Release boundary

`hardware/revB/gates.json:layout_allowed` remains `false`.
The following cannot be inferred from passing ERC, source audits or RTL simulation:

- real DUT neutral/permit thresholds, leakage, cable-fault response or shutdown time;
- board thermal, MLCC bias/aging and magnetic loss/saturation qualification;
- DAC stability/accuracy and ADC analog precision/sample-rate qualification;
- powered-off backfeed and cable transient behavior;
- Vivado STA/IO DRC until reports bound to the exact source/top/part/XDC are imported;
- EMC, fault injection or FOC closed-loop acceptance on physical hardware.

The next engineering step is therefore evidence/physical binding, not adding more
functional schematic pages.

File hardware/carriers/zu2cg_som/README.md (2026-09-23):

# ZU2CG SoM carrier binding (not selected)

This is an alternative to AXU2CGB, NOT another FPGA connected to it.

The common logical contract is `hardware/revB/io_contract.json`. A native physical
project/XDC cannot be generated while this profile is UNBOUND. To bind a module:

1. Select an exact vendor/module/hardware revision and archive its interface evidence.
2. Populate a separate `physical_pinout.csv` (connector,pin,board_signal,soc_ball,
   bank_group,voltage,kind,source), with no functional net names mixed in.
3. Populate `assignments.csv` (net,connector,pin) from the common contract.
4. Record the canonical CSV SHA256, vendor power/boot contract and FPGA device.
5. Set status to BOUND_CANDIDATE, not PASS. Run the same validator and native
   netlist/ERC checks. Binding does not close hardware validation gates.

The current generator accepts only physically matching common voltage domains.
A module with only 1.8V HP pins needs actual reviewed 3.3V translation/PHY changes;
the validator deliberately rejects voltage mismatch rather than silently aliasing
it. The fixed common I/O design is reusable; the carrier power, level conversion,
connector layout and exact balls are not vendor-independent.

A purchased module is responsible for SoC BGA, DDR, boot storage and internal
core supply. The carrier must supply only the vendor-required module input(s),
not a guessed copy of the removed local-FPGA power tree.

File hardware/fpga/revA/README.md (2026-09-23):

# Rev.A Local I/O FPGA pin planning

Candidate device: **XC7A35T-1FGG484I**.

Exact PACKAGE_PIN assignments are intentionally not guessed. Generate them in Vivado I/O Planner after bank voltage, clock-capable pin and escape requirements are reviewed.

| Function | VCCO | Requirement |
|---|---:|---|
| configuration/QSPI/debug | 3.3 V | compatible flash/JTAG |
| HIL-Link | 1.8 V | source-synchronous 100 MHz DDR; clock-capable input pin |
| AD3542R digital | 1.8 V | SCLK/CS/SDIO/LDAC/RESET |
| future I/O | TBD | reserved for Rev.B |

Before schematic freeze:
- fill real FGG484 balls in `pin_plan.csv`;
- generate `servohil_io_revA.xdc` with PACKAGE_PIN and IOSTANDARD;
- add HIL-Link timing constraints;
- cross-check schematic pins against XDC;
- pass Vivado DRC for bank voltage and clock placement.

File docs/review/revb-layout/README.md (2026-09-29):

# Rev.B PCB Layout — Phase 1

## Scope

PR #30 closed the **schematic/Layout-entry gate**. This phase therefore does not reopen the 15-page schematic architecture. The active sequence is:

1. carrier mechanical reference, board outline, mounting holes, connector placement and keepouts;
2. six-layer stackup and design rules;
3. power and precision-analog placement;
4. grounding and return-path control;
5. routing;
6. KiCad PCB DRC and layout review.

The source-of-truth contracts are:

- `hardware/revB/pcb_layout_contract.json`
- `hardware/revB/pcb_design_rules.json`
- `hardware/revB/layout_entry_contract.json`

`layout_allowed=true` remains independent from `fabrication_allowed=false` and
`release_allowed=false`.

## Mechanical baseline

The original AXU2CGB exposes J12 and J15 as two 40-pin, 0.1-inch / 2.54 mm
expansion ports. The repository already binds the logical pinout in
`hardware/carriers/axu2cgb/physical_pinout.csv` and the 64 used signals in
`assignments.csv`.

The schematic intentionally represents J12/J15 as **purchased-host logical
boundaries** with `on_board=no`. That was correct for schematic closure, but a
directly mated PCB requires a physical expansion-board mating connector and exact
mechanical registration.

The pinned manufacturer DXF now binds the 100 x 85 mm host outline, four primary
mounting holes, both 2x20 pin grids, J12/J15 geometric centers, and pin-1
orientation. Pin 1 is the non-circular square `PIN_TOP` pad: J12 is at
`(6.5278, 18.3769)` and J15 at `(93.4720, 66.6369)` in ALINX DXF native mm.

The remaining mechanical inputs that must be bound before a real mating
connector footprint / stack is released are:

- exact host connector manufacturer/MPN and expansion-board mating MPN;
- mated stack height;
- tall-component / heatsink / connector keepouts.

**Do not scale a product photograph into manufacturing coordinates.**

These remaining items are PCB mechanical inputs, not a reason to return to broad
schematic redesign. Until connector MPN/stack height is bound, PR #31 keeps the
native `.kicad_pcb` intentionally absent rather than committing a guessed generic
2x20 footprint. If direct mezzanine mating is selected, the only schematic
adjustment should be the minimum reviewed representation needed to give the
physical mating connectors real nets/ratsnest connectivity.

## Stackup target

Use a six-layer role stack while the manufacturer-specific dielectric geometry is
still unbound:

| Layer | Role |
|---|---|
| L1 / F.Cu | components + signals |
| L2 / In1.Cu | continuous GND reference |
| L3 / In2.Cu | power distribution + slow signals |
| L4 / In3.Cu | signals |
| L5 / In4.Cu | continuous GND reference |
| L6 / B.Cu | components + signals |

Nominal total thickness is 1.6 mm only as a mechanical target. Copper thickness,
dielectric thickness, finished impedance geometry and via capability must be
rebound to the chosen PCB fabricator before fabrication release.

## Grounding / return path

The board uses **continuous reference planes with functional zoning**, not hard
AGND/DGND islands.

- Keep L2 and L5 continuous GND.
- Separate switchers, digital PHY, ADC and DAC by placement and current-loop
  geometry.
- Never route a fast or precision signal across a reference-plane void.
- Put a nearby GND stitching via next to each high-speed layer transition.
- Keep switching current return loops local.
- Put connector ESD return vias immediately beside the protection device.
- J5 pins 9/10 are signal GND, not chassis/PE.

## Placement order

### 1. Input power

Place in physical current-flow order:

`J101 -> F101 -> D101/D102 -> U101 -> C105`

Keep TVS/eFuse/bulk paths compact and reserve an edge-access zone for J101 and
SW101.

### 2. Switching power

Treat each converter as a compact island:

- U201/L201 — 6V2_PRE
- U202/L202 — 3V3_D
- U203/L203 — 1V8_D
- U301/L301/L302/D301/C410/C411 — negative preregulator

The SW-node copper is intentionally small. Do not route it under or adjacent to
ADC, DAC, reference or low-noise LDO networks.

### 3. Low-noise rails and precision analog

Place U211/U212/U302 downstream of the switching stages and close to their
precision loads. Cluster U20-U23 with local decoupling/output networks. Orient
the DAC region so digital traffic enters from the host side and AO paths leave
toward J5.

For U801, keep reference/REGCAP/decoupling and the input RC network compact.
Connector-side protection is physically before the ADC victim.

### 4. External PHY

For encoder/RS-485 paths, use:

`external connector -> protection -> termination/transceiver -> digital logic`

Keep the A/B pair coupled and free of long stubs. A 120-ohm differential target
is a **target**, not a released width/gap, until the board shop stackup is
selected.

## Baseline geometry

The current layout target is intentionally conservative for prototype-capable
fabrication:

- default clearance: 0.20 mm;
- default signal width: 0.20 mm;
- default via: 0.60 / 0.30 mm;
- copper-to-edge: 0.30 mm;
- VIN_RAW/VIN_PROT: polygon or >=1.00 mm trace when not poured;
- medium-current rails: polygon or >=0.50 mm trace when not poured.

These dimensions are Layout defaults, not a manufacturer process approval.

## Routing priority

1. switching hot loops and power current paths;
2. precision reference / DAC / ADC analog;
3. external differential pairs;
4. fast DAC/ADC digital groups;
5. safety handshake/control;
6. remaining low-speed signals.

The fast J12 ADC/DAC buses must remain compact over an uninterrupted GND
reference, with no long stubs and few vias. Numeric skew limits are not invented
here; they are closed later with the functional timing contract.

## PCB DRC close criteria

Layout close requires:

- zero unconnected items;
- zero clearance, width, via and board-edge violations;
- all courtyard overlaps reviewed and no unwaived conflict;
- connector keepouts and access envelopes reviewed;
- a selected-fabricator stackup before controlled-impedance geometry is treated
  as closed.

Passing PCB DRC does **not** authorize Gerber/fabrication.

## Gates that remain outside Layout entry

The following remain fabrication/release gates and continue in parallel without
blocking placement/routing:

- manufacturer MLCC/magnetics curves;
- real DUT adapter thresholds/leakage/shutdown timing;
- partial-power/backfeed;
- assembled-board thermal;
- low-energy fixture/fault injection;
- Vivado raw I/O DRC and functional STA/CDC;
- EMC, power-down, fault injection and FOC closed-loop acceptance.

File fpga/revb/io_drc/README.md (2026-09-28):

# Rev.B AXU2CGB Vivado I/O DRC harness

This directory is a **constraint-validation harness**, not the functional ServoHIL FPGA top.

It exists to answer one narrow question before functional integration:

> Do the current Rev.B AXU2CGB package-pin and IOSTANDARD assignments load and pass strict Vivado I/O DRC for the bound device `xczu2cg-sfvc784-1-e`?

It deliberately does **not** claim functional timing, latency, CDC correctness, plant execution, ADC timing, PWM capture timing or a production bitstream.

## Inputs

- target part: `xczu2cg-sfvc784-1-e`
- top: `servohil_io_drc_top`
- port contract: `hardware/revB/io_contract.json`
- physical assignment provenance: `hardware/carriers/axu2cgb/profile.json` plus the native `carrier.xdc.preview`
- harness XDC: `axu2cgb_io_drc.xdc`

The harness XDC is only approved for this I/O-DRC scope. It contains package-pin and IOSTANDARD assignments only. It is not the future functional timing XDC.

## Run

From repository root with Vivado on PATH:

```sh
digest="$(python tools/revb_vivado_io_evidence.py source-digest)"
vivado -mode batch -source fpga/revb/io_drc/run_io_drc.tcl -tclargs build/revb-vivado-io-drc "$(git rev-parse HEAD)" "$digest"
```

PowerShell:

```powershell
$digest = python tools/revb_vivado_io_evidence.py source-digest
vivado -mode batch -source fpga/revb/io_drc/run_io_drc.tcl -tclargs build/revb-vivado-io-drc $(git rev-parse HEAD) $digest
```

Expected raw outputs:

- `report_drc.rpt`
- `report_io.rpt`
- `report_utilization.rpt`
- `io_drc_placed.dcp`
- `io_runtime.csv`
- `drc_summary.json`
- `run_identity.txt`

The Tcl exits non-zero when Vivado reports an Error or Critical Warning DRC violation.

## Evidence boundary

A successful local command is not yet a checked-in PASS. The raw reports must be imported through the Rev.B source-bound evidence envelope with:

- exact source commit/digest;
- exact target part and harness top;
- Vivado version;
- raw report path and SHA-256.

Functional STA remains blocked until a real functional top, clock/generated-clock definitions, I/O delays and timing/CDC policy are bound.

## Import source-bound raw evidence

After a successful Vivado run, validate the raw directory independently:

```sh
python tools/revb_vivado_io_evidence.py validate-run build/revb-vivado-io-drc
```

Then prepare a non-overwriting evidence pack under the repository top-level
`evidence/` directory:

```sh
python tools/revb_vivado_io_evidence.py prepare \
  build/revb-vivado-io-drc \
  evidence/revb/vivado_io_drc/<run-id> \
  --source-commit "$(git rev-parse HEAD)" \
  --reviewer "<reviewer>" \
  --reviewed-on YYYY-MM-DD
```

The prepared `evidence.json` may be registered as
`prelayout_evidence_status.json -> vivado -> VIVADO_IO_DRC` only after review.
The importer checks the Vivado runtime I/O table against all 64 expected pins and
I/O standards, requires zero Error/Critical Warning DRC findings, SHA-256 binds
every retained raw artifact, and rejects a raw run whose recorded source digest
does not exactly match the current repository source.

This still leaves `VIVADO_TIMING=NOT_RUN`.

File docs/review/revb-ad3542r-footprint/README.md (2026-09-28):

# AD3542RBCPZ16 / CP-28-15 footprint evidence review

**Date:** 2026-09-28  
**Scope:** U20..U23 exact land-pattern closure for Rev.B.  
**Result:** **RESOLVED IN SOURCE — official EVAL Gerber/BOM and current package documentation reviewed; Layout remains blocked.**

## Exact device and package identity

The active DAC is **Analog Devices AD3542RBCPZ16**. Current Rev.C documentation
identifies package option **CP-28-15**, a 28-lead LFCSP with a 4 mm × 4 mm body,
0.95 mm nominal height and 0.40 mm pitch.

Manufacturer sources remain:

- product/CAD entry:
  https://www.analog.com/en/products/AD3542R.html
- Rev.C data sheet:
  https://www.analog.com/media/en/technical-documentation/data-sheets/ad3542r.pdf
- CP-28-15 package drawing:
  https://www.analog.com/media/en/package-pcb-resources/package/pkg_pdf/lfcspcp/cp-28/cp-28-15.pdf
- EVAL-AD3542RFMCZ Gerber:
  https://wiki.analog.com/_media/resources/eval/user-guides/dac/eval-ad3542r/09-050892-01c.zip
- EVAL-AD3542RFMCZ BOM:
  https://wiki.analog.com/_media/resources/eval/user-guides/dac/eval-ad3542r/05-050892-01-d.xlsx

The official EVAL files are also discoverable through the Analog Devices public
documentation repository at
`analogdevicesinc/system-level@76eb29d83e6eaca9ce4470921d315938b2b1aa17`.

## Source artifacts reviewed

The review pins the exact downloaded artifacts by SHA-256 rather than redistributing
manufacturer binary files:

| Artifact | SHA-256 |
| --- | --- |
| `ad3542r.pdf` Rev.C | `a9536b981e1dc140082ddff947487faaaa47874cd8b648966ee9c6b92fa292fa` |
| `cp-28-15.pdf` | `f6aab2aa746e79a01b4d9067bde56c886001a4cb1b7ed83e198d480ab0845b73` |
| `eval-ad3542r-ug-2258.pdf` | `ed5afa177bce6c907a3981c71f49cc3964078a6b6ff79ecfd24ae78f6a1093b4` |
| `09-050892-01c.zip` | `87eee7f3ed85e81798918b1977bc0b416d72699a39c771d95e9ea3839ef461e8` |
| `05-050892-01-d.xlsx` | `4608d8884754e5768424832af2331fa0490ab90e05a990a1292bf8f7bab0f7df` |

The deterministic review record is:

`hardware/revB/evidence/ad3542r/u1_geometry_review.json`

It retains source/member hashes, all 28 U1 IPC-356 records, the exact Gerber U1
flash coordinates/apertures, the EVAL BOM U1 identity and the canonical KiCad pad
mapping.

## Official EVAL U1 identity

The EVAL BOM binds:

- reference: **U1**
- manufacturer: **ANALOG DEVICES**
- manufacturer part: **AD3542RBCPZ16**
- JEDEC field: **QFN28_4X4**

The IPC-356 file contains exactly U1 terminals **1 through 28**, with 0.40 mm pitch.
There is no U1 terminal 29 or exposed-pad terminal.

## Exact reviewed land pattern

The EVAL U1 pad-center offset from package center is **1.8933 mm**.

Official Gerber apertures are:

| Layer | Side pads | Top/bottom pads |
| --- | --- | --- |
| Top copper `L1_TOP.art` | 0.7366 × 0.2286 mm obround | 0.2286 × 0.7366 mm obround |
| Top paste `PMT.art` | 0.7366 × 0.2286 mm obround | 0.2286 × 0.7366 mm obround |
| Top solder mask `SMT.art` | 0.8382 × 0.2794 mm obround | 0.2794 × 0.8382 mm obround |

All three layers resolve exactly 28 perimeter positions for U1.

The local source footprint is:

`Package_DFN_QFN:AnalogDevices_CP-28-15_AD3542R`

at:

`hardware/kicad/revB/axu2cgb_expansion/footprints/Package_DFN_QFN.pretty/AnalogDevices_CP-28-15_AD3542R.kicad_mod`

Numbered pads reproduce the official EVAL copper/paste dimensions. Independent,
unnumbered F.Mask aperture pads reproduce the asymmetric official solder-mask
openings rather than approximating them with one isotropic mask expansion.

## Center/exposed-pad decision

The earlier preliminary-document ambiguity is now resolved for the current
manufacturing decision.

The following current evidence agrees:

1. Rev.C pin configuration enumerates pins 1..28 without an exposed-pad terminal.
2. CP-28-15 bottom view shows 28 perimeter terminals and no center pad.
3. EVAL IPC-356 contains exactly U1 pins 1..28.
4. EVAL top solder-mask and paste files contain 28 perimeter apertures and no center
   aperture.

Therefore the reviewed footprint **must not add a center/exposed pad**.

Several unrelated small copper/via flashes exist under the 4 mm × 4 mm body
projection on the EVAL PCB, but they have no matching U1 pin in IPC-356 and no
center F.Mask/F.Paste aperture. They are board routing/via features, not an exposed
package land.

## Rev.B binding result

U20, U21, U22 and U23 are now bound to the reviewed footprint and their displayed
value is the exact `AD3542RBCPZ16`.

`hardware/revB/schematic_open_items.json` records them under
`resolved_bindings`, not `open_footprints`.

The closure checker independently verifies:

- the exact source artifact/member hashes;
- EVAL BOM U1 identity;
- all 28 IPC-356 pins and Gerber aperture groups;
- no center pad/mask/paste aperture;
- 28 numbered KiCad copper/paste pads;
- 28 explicit KiCad F.Mask aperture pads;
- exact coordinates and dimensions;
- native U20..U23 value/footprint bindings.

## Boundary of this closure

This closes only the **exact physical package land-pattern blocker** for U20..U23.

It does **not** establish:

- DAC static/dynamic accuracy on the Rev.B board;
- output stability with the real DUT/cable;
- thermal qualification;
- EMC;
- manufacturing process qualification;
- complete PCB placement/routing;
- permission to enter Layout.

`layout_allowed=false` remains invariant until the remaining pre-layout gates and
engineering review are complete.

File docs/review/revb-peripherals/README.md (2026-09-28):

# Rev.B ADC / PHY / health / connector-protection implementation — PR #22 + PR #23 + schematic closure

Engineering continuation from main `37a4463dbf956cdefe1d55922078de9e327a287b`
after merged PR #21. **Non-release native circuit implementation. No fabrication,
board measurement, full DUT inhibition or functional-safety approval.**

## Source and implementation

The native circuit commit is `90247a6df219d9f0e203d16366d70aad0cb9fd55`.
The root project now has 15 sheets. J3/J4 remain removed; 37 connector-side ESD/transient devices are placed directly in the owning 03/06/50/70/80 sheets without changing the 64-signal carrier allocation. The current source audit counts 439 in-BOM/on-board physical instances after excluding purchased-host J12/J15 from expansion-board placement. The independent peripheral oracle now also asserts every protection-device pin/net/package identity. Existing power/DAC wiring remains frozen except explicitly reviewed safety/protection shunts.

| Sheet | Circuit | Deliberate limit |
|---|---|---|
| 70_adc_frontend | U801 AD7606C-16BSTZ; eight single-ended inputs; two 100-ohm series legs and a 1nF differential capacitor each; explicit supply/reference/regulator capacitors; eight DOUT lanes and host controls | Low-energy candidate, not field-input surge protection or qualified 16-bit acquisition |
| 80_encoder_phy | Four THVD1450 half-duplex pairs for two clock/data ports; four safety-gated DE controls; pull defaults and selectable termination | SSI/BiSS directional profile, not arbitrary ABZ or SPI compatibility; non-isolated, no encoder supply |
| 03_peripheral_boundaries | Six SN74LVC541A PWM receive paths; gated THVD1450 RS485; six AUX logic pins and I2C | 3.3V laboratory logic, not a 24V PLC/gate-drive input |
| rtl/revb/health_heartbeat.sv + runtime_health_integration.sv | Sequence/deadline/lease-qualified WDI/ARM fed only by completed Plant, ADC sample and lease-renew events | AXI/CDC/top-level/Vivado and physical fault-injection integration remain open |
| in-page connector protection | PESD15VL1BA on AI/AO, PESD5V0S1BA on low-voltage logic, SM712 on differential cable pairs | Schematic protection only; IEC ESD/surge, return path/layout and powered-off backfeed remain NOT_RUN |

Most physical components now have explicit footprint identifiers backed by project-local KiCad snapshots. `hardware/revB/schematic_open_items.json` intentionally retains 14 blank-footprint blockers for exact vendor land patterns or real mechanical/connector choices; CI rejects any unlisted blank footprint. This is still **not** production package/MPN/lifecycle or board-level qualification.

## ADC configuration and electrical interface

AD7606C-16 (not legacy AD7606) allows the allocated 1.8V digital supply. AVCC uses
+5V0_DAC, not +5V2_PVDD. All four AVCC and all grounds are wired. REGCAP_A and REGCAP_D use
separate 1uF capacitors; REFIN/OUT has 100nF; the two REFCAP pins share only their
10uF capacitor. The internal reference is selected. OS[2:0]=111 selects software
mode; SER/PAR is strapped serial, STBY is inactive and WR high. Unused parallel
pins are grounded per serial-interface guidance. RESET and CS have pullups;
CONVST/SCLK/SDI have pulldowns. Controls and return data have series resistors.

An eight-lane connection does not select eight-lane mode by itself. PR #23 adds `ad7606c16_controller.sv`: initialization writes CONFIG register 0x02 for eight DOUT lanes, verifies readback before `configured`, then sequences CONVST/BUSY and captures eight 16-bit lanes before asserting `sample_valid` and advancing `sample_seq`. `runtime_health_integration.sv` consumes that completed sequence rather than a conversion request. Analog calibration, sample-rate/settling qualification, CDC/top-level binding and real ADC-to-Plant hardware integration are still open.

J801 is paired single-ended input/GND. Nominal intended range is +/-10V only for
a reviewed low-energy source. The IC's clamp and absolute-maximum specifications
do not qualify external fault energy, cable surge, unpowered input or leakage.
100-ohm legs and 1nF are a candidate EMI/source network, not a complete external
anti-alias filter. R/C type, tolerance, temperature coefficient, fault dissipation
and connector constraints must be bound before assembly.

## Differential roles and host binding

For each encoder port, IO0 -> pair0 D, pair0 R -> IO1, IO2 -> pair1 D,
pair1 R -> IO3. DIR0/1 request transmit and are gated with SAFE_ENABLE. Receiver
RE_N pins are tied low (always receive). The generic carrier inout declaration
must not be mistaken for arbitrary reassignment: drive IO0/2 only; receive IO1/3.
Configure tri-state/CDC/top-level directions accordingly before a real bitstream.

SSI/BiSS master role: DIR0=1 (clock transmit), DIR1=0 (data receive). Emulated
slave role: DIR0=0, DIR1=1. Select roles only while disarmed and validate bus-idle
and contention response. Four-wire SPI and three differential ABZ pairs are not
supported by this physical profile. No encoder power is sourced on J901/J902.

J1004 is RS485 A/B/GND; transmit request similarly requires SAFE_ENABLE.
All 120-ohm termination jumpers ship unshunted in this design. Install only for
the reviewed role/cable ends; receiver always-on may see local transmit echo.
Non-isolated buses, host-off backfeed through receiver/AUX/I2C paths, DE ramps, common mode, line length and turn-around delays still require review. The new TVS sheet addresses the missing schematic clamp topology but does not convert ESD/surge or partial-power gates into PASS.
SAFE_ENABLE gating alone is not a partial-power or single-fault safety proof.

The fixed 64-signal carrier contract contains no independent CAN controller or
EtherCAT slave interface. Those were an overbroad earlier README description.
Adding them requires an explicit controller/PHY/clock/power/pin allocation and
review; no spare AUX signal was silently repurposed. An external Raspberry Pi
EtherCAT host is not a populated PHY on this expansion board.

## Native-value load and RC screening

`sim/peripherals/screen.py` reads the actual component values and combines them
with the existing regulator limits. The output always has qualification=BLOCKED,
layout_allowed=false and physical_tests=NOT_RUN. `--strict-design` returns 2.
The 9 regression tests include changed RC/termination/MPN and invalid parameters.

Current analytical results (not measurements):

| Quantity | Screen | Interpretation |
|---|---:|---|
| ADC AVCC static limits | 4.883310..5.096890V | Within IC static operating window; startup/transient still unqualified |
| ADC VDRIVE static limits | 1.772118..1.811926V | Within C-16 static window; not proof of 40MHz board timing |
| External 100+100ohm / 1nF pole | 795.775kHz | External-only first-order network; excludes the internal ADC filter |
| External attenuation at 500kHz | -1.445dB | Cannot serve as the sole anti-alias qualification |
| External full step to 0.5LSB | 2.357us | Simplified linear RC calculation, not IC acquisition/settling specification |
| Positive-leg simplified DC gain loss | 99.990ppm; 3.276LSB at +10V | Assumes 1Mohm input load, excludes other ADC errors; calibration/error budget remains |
| Five enabled PHY resistive-load stress | 323.704mA | VCCmax/54ohm + 3mA no-load each, not dynamic or short-circuit qualification |
| Local 120ohm termination dissipation | 93.566mW | Worst VCC across -1% nominal resistor, not all-temperature component rating |
| 3.3V additive allocation need | 648.704mA | Retains all old 300mA plus load stress and assumed 20mA dynamic/5mA logic reserve |

The earlier full budgets are conservatively retained, even if they included
unused headroom. Updated EDV loads are 3V3_D=0.70A, 1V8_D=0.32A,
6V2_PRE=0.55A and +5V0_DAC=0.25A. This is allocation, not measured consumption or
a supply capability guarantee. Firmware normally transmits only two encoder
pairs plus optional RS485; five transmitters is an allocation stress case, not
an approved bus role. The 250mA component short-circuit magnitude and all-five
short scenario show why loaded/fault thermal and upstream limits remain open.

These new loads feed the existing 25-case ngspice and analytical reports.
The unchanged rail-setpoint/headroom conflict, vendor closed-loop model gap,
MLCC curves, magnetic/thermal qualification, input energy and AON/partial-power
blockers are not cleared by this extension. No regulator set resistor was changed
merely to hide the earlier failing margins.

## Verified pre-commit native checkpoint

The source was authored in a branch-scoped disposable checkout, checked by real
KiCad, then its immutable blobs were inspected and committed. Temporary writers
and their write-enabled workflow were removed in the native commit. Normal CI
never redraws or overwrites the source.

- Workbench run 36026084609, input HEAD d1a2ecbe0fc6151a8730f20c68af2aa615284222.
- Artifact 10819538628, `revb-peripheral-precommit-review`.
- ZIP SHA256 c51a666311c14577a89300f967e87d62e93c2c9e94f02386cf8378beb9fe27c6.
- Scope is explicitly PRECOMMIT_SCRATCH_NOT_HEAD_EVIDENCE. It is **not** proof that
  the unmodified input HEAD already contained the new native circuit files.
- Historical PR #22 checkpoint: KiCad 10.0.6, 15 pages, 0 ERC violations. Current 15-page closure must use the latest branch/PR artifact; do not reuse this old count as current evidence.
- 20 native/checker/library objects checked against both Git blob SHA and SHA256;
  downloaded native bytes match the locally inspected files.
- 166 regression tests passed, 0 skipped, including actual Icarus and ngspice.
  Peripheral mutations include 15 deliberate ADC/PHY/wiring errors; earlier
  safety mutations remain. New source tests were observed failing before circuit
  implementation; screen tests likewise failed before the analysis/budget change.
- The three changed/new PDF pages were visually reviewed; the title-block and
  label collisions found in the first run were corrected before native commit.

For committed-HEAD acceptance, use the latest PR native and EDV artifacts instead
of reusing this scratch checkpoint. They record the actual source/merge-test SHA;
PR branch SHA and GitHub synthetic merge SHA may differ. The native CI stores
full test log, XML, ERC, PDF and source ZIP. The compact EDV artifact is only a
report/source index; full raw SPICE files remain in the full EDV artifact.
Review was inline, not an independent human/agent hardware approval.

## Actual DUT safety: mandatory unresolved binding

Do not choose a generic zero voltage, pull resistor or shutdown deadline for an
unknown DUT. Before low-energy acceptance, record the actual DUT/adapter model
and schematic revision; AO input transfer/neutral window/source impedance; the
permit input threshold/current/leakage; cable connections, grounds and supply
sequences; and the maximum allowed hazard-reaction time. Review the independent
energy-removal arrangement before any motor-powered testing.

| Acceptance item | Required raw observation / acceptance basis |
|---|---|
| Cold boot and ARM held high | No permit or unintended AO connection while WDI missing/static or while hardware qualification is pending |
| Health faults | Stop Plant completion, I/O completion or host lease separately; replay a duplicate sequence; capture WDI, ARM, SAFE_ENABLE, AO, permit contact and real DUT input on one timebase |
| Fault recovery | Restore supplies/progress/contact while ARM remains high; require continued inhibition until explicit recovery and new ARM transition |
| AO neutral state | Measure every DUT input when switch off, cable removed and supplies sequenced; compare against the DUT-specific neutral window, not nominal 0V |
| Permit leakage/cable loss | Worst component leakage, open cable, brownout and unpowered adapter must yield the DUT-specific inhibited state |
| End-to-end reaction | Add detection, logic, switch/PhotoMOS, cable/DUT filter and DUT reaction; compare the measured total with the reviewed DUT hazard budget |
| ADC/PHY electrical | Distinct bounded input patterns, calibrated DC/AC/error/noise, serial timing, termination/roles, contention, PWM glitches and powered/unpowered cable cases |
| Production evidence | Exact PCB/HW revision, BOM lots, FW/bitstream SHA, equipment/calibration, conditions, raw thermal/EMC/transient/fault/FOC traces and engineering sign-off |

All physical cases above are NOT_RUN. A resistor calculation, a component rating,
a synthetic fixture or passing ERC cannot be filed as a physical PASS. The
existing release-gate file remains unchanged. No PCB/Gerber or production release
is included in this PR.

## Primary component references

- [ADI AD7606C-16 Rev.A](https://www.analog.com/media/en/technical-documentation/data-sheets/ad7606c-16.pdf): pins pp15-17, supply/current/input tables, serial software configuration and decoupling guidance.
- [TI THVD1450 Rev.E](https://www.ti.com/lit/ds/symlink/thvd1450.pdf): pin table, loaded/no-load conditions, DE/RE and power-off limitations.
- [TI SN74LVC541A Rev.O](https://www.ti.com/lit/ds/symlink/sn74lvc541a.pdf): PW20 pin mapping and Ioff/logic limits.
- [TI SN74LVC1G08 Rev.Z](https://www.ti.com/lit/ds/symlink/sn74lvc1g08.pdf): DBV pin mapping and logic limits.
- [TI TPS3430](https://www.ti.com/lit/ds/symlink/tps3430.pdf): external watchdog timing; standalone RTL simulation does not verify the complete hardware timing chain.

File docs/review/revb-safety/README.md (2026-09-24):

# Rev.B hardware safety continuation — 2026-09-24

**Native circuit implementation checkpoint. Electrical design BLOCKED; no PCB,
fabrication, complete-DUT-inhibit or functional-safety sign-off.**

[PR #21](https://github.com/magic-alt/servoHIL/pull/21) continues from main
`c29abb07e9fca5584235860dbe7f2bd1460141ca`, after merged PR #20/#18.
The native circuit commit is `3af3ab79177c31b2c46e7233b07dbd12985c1451`.
There is still one ZU2CG. No ADC/PHY expansion, Rev.A file change or release-gate
promotion is part of this continuation.

## What is now a real native circuit

| Sheet | Added implementation | Remaining qualification |
|---|---|---|
| 50_watchdog_interlock | U501 TPS3430; U504/U505 input buffer/inverter; U502/U509 dry-contact/AON reset; U510 reset buffer; U506/U507 two-edge qualification; U503 delayed release into RAILS_OK; U508 three-input SAFE_ENABLE | Partial power, timing/clock skew, startup/reset propagation, host/PL heartbeat semantics, package review and physical fault injection |
| 06_analog_outputs | U601/U602 ADG5412F: eight normally-open switches; protected S faces DUT, D faces DAC; two independently pulled-down IN groups; bypass capacitors and FF test points | RON, settling, charge injection, voltage headroom, off leakage, fault energy and actual DUT neutral state |
| 60_dut_permit | U701 AQY212GS; Q701 MMBT3904; LED/base current limiting and base pulldown; J701 floating normally-open contact | Final package, LED-current/thermal corners, actual DUT threshold/leakage/cable-loss response and measured shutdown time |

The project is 13 pages, 263 physical components (216 retained + 47 added).
Existing physical pin relationships are frozen except the eight explicitly
rerouted J5 output contacts. `40_power_supervision` only promotes RAILS_OK to a
cross-sheet label; no old physical circuit was silently replaced.

## Interface contract — implementation is not system qualification

`HIL_WDI` is J15.33 and `HIL_ARM` is J15.32 in the existing AXU2CGB binding.
WDI is buffered with an Ioff-capable part. TPS3430 uses **falling-to-falling**
intervals: nominal 5 ms, requested contract 4..6 ms. A square-wave implementation
therefore toggles every 2.5 ms at nominal timing, not once every 5 ms. SET0/SET1
are hard-high; CWD is through 10k to AON. There is no firmware-controlled watchdog
bypass. Factory lower-window corners are 1.48/1.85/2.22 ms; upper corners are
9.35/11/12.65 ms. CRST open selects 170/200/230 ms reset hold; initial evaluation
and startup are additional and not simulated by the discrete reference.

WDI must attest completed real-time Plant/I/O deadlines and a valid host/session
lease. An unconditional free-running PL timer can keep the watchdog healthy
while the useful system has failed. **This PR does not implement or verify that
firmware/RTL health producer.** Deliberate recovery must first hold ARM low,
restore qualified rails/interlock/heartbeat, then issue a fresh ARM rising edge.

U502 supervises AON and the local 3.3 V dry-contact interlock. U510 buffers the
open-drain clear into the two DFFs. Two observed heartbeat edges set HB_VALID;
U503 adds its open-drain inhibit to existing RAILS_OK. CT open has a 12..28 ms
release range, not an exact 20 ms delay. RAILS_OK clears the existing ARM latch.
It does not feed back into the heartbeat clear path. A recovered watchdog,
restored rail or closed interlock cannot re-arm the board while ARM stays high.
SAFE_ENABLE = RAILS_OK AND ARM_LATCH AND HIL_ARM, with a default pulldown. The
existing 1.8 V DAC reset gate remains separate from the new AON-domain enable.

AO OFF means **high impedance, not zero voltage or a safe neutral**. The reviewed
DUT adapter must establish its own neutral bias and respect the separate permit.
FF outputs currently terminate only at local test points; their guaranteed
logic-level margin to an aggregate interlock is unresolved. A channel's internal
fault protection is not a verified global DUT inhibit.

J701 is a proposed SELV <=24 V / <=10 mA permit interface, not a board-qualified
rating. Its two contact nets have no copper connection to board GND or a supply.
R701=220 ohm, R702=680 ohm and R703=10k are candidate drive values. AQY212GS
component specifications include <=1 uA off leakage and recommended 5..30 mA LED
drive; these do not prove the actual DUT's inhibited state. The new AON load and
all-temperature LED/transistor/logic margins need qualification. It is not motor
power switching, not redundant, and not a certified STO output. A shorted relay,
shorted AO switch or stuck-high enable is not covered by a single-fault safety
claim. Motor-powered testing needs an independently reviewed energy-removal and
emergency-stop arrangement.

## Evidence checkpoint (downloaded native artifact, not inferred from green CI)

- PR head: `3af3ab79177c31b2c46e7233b07dbd12985c1451`.
- GitHub PR merge-test/source commit: `3117c13c24374dd03cdf32a1596ac2ab7e9e1f49`.
- [Native read-only CI run](https://github.com/magic-alt/servoHIL/actions/runs/36010821083): PASS;
  artifact `10812267969`, `native-schematic-readability`.
- Artifact SHA256: `29998d925aba9bdb6a6bc8bc47bfc261139732f4941a4352715f2b3c03353927`.
- 42 archived native source files compared byte-for-byte with the inspected
  source; actual KiCad **10.0.6**, 13 sheets, **0 ERC violations**, no suppressed
  rules/exclusions added. PDF pages for AO/watchdog/permit visually inspected.
- Frozen 216 old components; 47 new components, 168 new physical-pin assertions,
  explicit J5.1..8 delta, AO bypass and contact-isolation assertions: PASS.
- Local full repository suite with the actual native XML and real ngspice:
  **144 tests, 144 passed, 0 skipped**. Includes 12 watchdog/qualification/rearm
  tests and 11 native miswire mutation subcases. Source/model regressions were
  observed RED before their corresponding implementation and GREEN afterward.
- [Hardware structure CI](https://github.com/magic-alt/servoHIL/actions/runs/36010821133): PASS.
  Its prior main failure was the stale pre-PR18 archive hash. The guard now freezes
  the already merged snapshot `052a06c6e6e5b0ce23e94f75774a9f1cc7f3f167`; unknown
  trees and rollback to the old snapshot are rejected by new regression tests.
- [EDV CI](https://github.com/magic-alt/servoHIL/actions/runs/36010821141): PASS for
  execution/integrity, **not electrical qualification**. The existing workflow
  requires strict-design exit 2 and verifies the full source-bound simulation
  pack in CI. Raw EDV waveforms were not independently downloaded/re-audited in
  this continuation; this is distinct from the downloaded native evidence above.

The earlier bootstrap runs were pre-commit scratch evidence, not evidence of a
committed native HEAD. Their temporary writer workflow and both authoring helpers
were removed in `3af3ab7`. Ordinary validation only reads/exports native files.
For later revisions, use the latest PR run's native artifact: it contains the
PDF, source ZIP, XML, ERC and source-commit identity. GitHub may test a merge
commit rather than the branch HEAD; compare the recorded native bytes as well.
The older PDF in `docs/review/revb-readability/` is the historical 11-page version.

Review was performed inline; the separately coded pin oracle is not a claim of
independent human or separate-agent design approval. No board measurement occurred.

## Planned physical acceptance — all NOT RUN

Run only after power EDV and the test fixture are reviewed. Start with a
current-limited, low-energy fixture and representative DUT input loads, not an
energized motor system. Capture AON, RAILS_OK, HB_VALID, ARM_LATCH, SAFE_ENABLE,
DAC_RESET_N, actual AO voltage/current and the J701/DUT input response on a common
timebase. Retain exact HW revision, part lots, firmware/bitstream SHA, supply/load,
temperature, instruments and raw traces. No stimulus API or Python truth model
can substitute for these observations.

| Test | Stimulus / required observation |
|---|---|
| SAFE-01 cold boot | WDI absent or static; ARM held high. No DUT permit, no AO connection or automatic startup, including watchdog retry grace periods. |
| SAFE-02 intentional ARM | 4/5/6 ms falling-edge intervals, healthy rails/contact; only a fresh ARM edge after qualification permits output. Check every AO channel with a reviewed neutral-bias/load fixture. |
| SAFE-03 stopped heartbeat | Stuck-high and stuck-low during enable. Capture detection and actual output/contact release. A DUT-specific maximum shutdown budget must be approved before assigning PASS. |
| SAFE-04 invalid window | 1 ms and 13 ms falling intervals plus burst/glitch sequences. Verify inhibition and no transient re-enable; test voltage/temperature corners. |
| SAFE-05 faults and recovery | Open dry contact; inject each reviewed rail fault; interrupt AON. Recover while ARM stays high. Require inhibited state until explicit disarm/re-arm. |
| SAFE-06 direct disarm | Drop HIL_ARM during valid heartbeat. Measure actual AO and DUT input reaction, not just the logic signal. |
| SAFE-07 partial power / cabling | Reviewed host-only, DUT-only and expansion-only supply combinations; remove cables. Measure Ioff/backfeed, neutral state, contact leakage and adapter response. |
| SAFE-08 analog / aggregate faults | RON/error/settling/charge injection/off leakage at selected rails and loads; bounded source-side faults with a reviewed energy-limited fixture; verify whether the application needs an aggregate FF inhibit. |

Before any release, close the existing DAC rail/headroom conflict, real regulator
startup/transient models, MLCC bias curves, magnetic/thermal qualification, new
AON current budget, device-package/connector/ESD review and all tests above.
ADC/PHY, layout and complete FOC HIL acceptance are separate unfinished stages.
`hardware/revB/gates.json` is unchanged; `layout_allowed=false`.

## Primary component references

- [TI TPS3430, SBVS366A](https://www.ti.com/lit/ds/symlink/tps3430.pdf): pins, fixed watchdog windows and reset timing.
- [TI TPS3808, SBVS050M](https://www.ti.com/lit/ds/symlink/tps3808.pdf): DBV pins, MR and CT timing.
- [TI SN74LVC1G74](https://www.ti.com/lit/ds/symlink/sn74lvc1g74.pdf), [G17](https://www.ti.com/lit/ds/symlink/sn74lvc1g17.pdf), [G14](https://www.ti.com/lit/ds/symlink/sn74lvc1g14.pdf), [G11](https://www.ti.com/lit/ds/symlink/sn74lvc1g11.pdf): pin functions, timing and logic limits.
- [ADI ADG5412F/ADG5413F Rev.C](https://www.analog.com/media/en/technical-documentation/data-sheets/ADG5412F_5413F.pdf): TSSOP pin table, protected S terminal and power-off behaviour.
- [Panasonic AQY212GS](https://na.industrial.panasonic.com/products/relays-contactors/semiconductor-relays/lineup/photomos-relays/series/12653/model/12659): LED/current/leakage/contact timing; not a board rating.
- [Nexperia MMBT3904](https://assets.nexperia.com/documents/data-sheet/MMBT3904.pdf): B1/E2/C3 and specified test-condition limits.

These component facts do not establish all-temperature, assembled-board or
system-level safety compliance. Final land patterns and DUT limits remain open.

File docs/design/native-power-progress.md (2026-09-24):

# PR17 native power implementation ledger

Scope: the user's approved single-SoC AXU2CGB expansion, native editable KiCad,
and real input -> regulated rails -> DAC supply/reference wiring. No PCB layout.
Branch: feat/revb-native-power-safety-dac.

## Recovery checkpoint
At 1baf66cf the remote PR had only devtool preparation, not the native schematic.
Earlier local screenshots are not a committed deliverable. This work adds and
commits each physical circuit section independently. Runtime execution is in
GitHub Actions, and outputs become native source, not just CI-only artifacts.

## Stage plan
1. Input: fuse/series reverse diode/TVS, TPS259474L latched circuit breaker,
   UVLO/OVLO/PGTH/ILM/dVdt/ITIMER, TPS70933 AON supply.
2. Positive rails: 6.2V preregulator, 3.3V and 1.8V bucks, +5.0/+5.2V low-noise LDOs.
3. Negative/reference: LT8330 dual-inductor inverting stage, LT3094 -5.2V,
   ADR4525 and explicit DAC decoupling/power paths.
4. Rail supervision: regulator PG and digital supervisors, power-good reset
   interlock and native full-hierarchy ERC. Full DUT safety remains separately qualified.

Each stage is a one-shot, refuses to overwrite existing child sheets, and is
committed after KiCad parses its actual netlist and pin-level checks pass.
A partial-stage parse is not full-board ERC or electrical qualification.

## Input design facts
TPS259474L is the adjustable-OVLO CIRCUIT-BREAKER/latch variant, not the active
current-limit TPS259470L. RILM=2.21k -> nominal 3334/2210=1.51 A trip setting.
Input pin divider 680k/60.4k/60.4k: UV~7.95 V, OV~15.91 V at VIN_EFUSE.
PGTH 56.2k/10k: ~7.94 V. Input rating remains regulated 9-15 V SELV, NOT a motor bus.
TPS70933 DBV pin 3 EN is OPEN per datasheet internal current pull-up: NEVER tie
it directly to 12 V (7 V absolute maximum). Output capacitance 4.7uF rated16V
requires >=2.2uF effective capacitance. AON budget <=15mA.

## Primary sources checked
- TI TPS25947 SLVSFC9C (May 2026), variant table p4, pin table pp5-6, design equations pp43-46: https://www.ti.com/lit/ds/symlink/tps25947.pdf
- TI TPS709 SBVS186H, DBV pins p3, output capacitance, EN open guidance p13: https://www.ti.com/lit/ds/symlink/tps709.pdf
- Diodes AP63200/1/3/5 DS41326 Rev3-2 (Nov2024): https://www.diodes.com/assets/Datasheets/AP63200-AP63201-AP63203-AP63205.pdf
- ADI LT3045 RevD, LT3094 RevB, LT8330 and AD3542R RevC.

All thermal, surge, effective-capacitance, loop stability and board-revision
measurements remain OPEN. Do not relabel candidate calculations as bench PASS.

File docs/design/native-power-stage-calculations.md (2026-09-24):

# Native Rev.B power design calculations — design inputs, NOT measured results

Supply range 9–15 V regulated SELV. Fuse + SS34 series diode + TPS259474L
circuit-breaker protect VIN_PROT. This is not a 48/67V motor-bus power input.
The selected current-trip is approximately 1.51 A, not a guaranteed continuous
output current. AON is deliberately limited to 15 mA.

## Positive conversion

AP63201WU-7: internally compensated 500 kHz forced PWM, pins FB1 EN2 VIN3 GND4
SW5 BST6. EN from eFuse INPUT_OK. Three independent stages:

| Rail | R upper / lower | Nominal | L | Board load budget |
|---|---|---:|---:|---:|
| 6V2_PRE | 67.3k / 10k | 6.184 V | 10 uH | 0.50 A |
| 3V3_D | 31.2k / 10k | 3.296 V | 6.8 uH | 0.30 A |
| 1V8_D | 12.4k / 10k | 1.792 V | 4.7 uH | 0.30 A |

Vout=0.8*(1+Ru/Rl). All dividers 0.1%; reference tolerance must also be included.
Each output has 2x22uF/16V X7R in 1210; actual part/DC-bias data must show at
least 20uF combined at operating voltage/temperature. Each bootstrap is100nF.
Inductors require Isat>=3A and DCR<100mOhm; exact manufacturer MPN remains BOM
qualification, not a fabricated claim of an already purchased part.

At VIN=15V, f=450kHz (conservative design assumption), L=80% nominal,
DeltaI=Vout*(Vin-Vout)/(Vin*L*f): approximately1.01A,1.05A,0.93A respectively.
Nominal budget peak currents are0.50+1.01/2=1.005A,0.30+1.05/2=.825A,
0.30+.93/2=.765A. These calculations do not prove startup/current-limit or
transient stability, and exact switching-frequency bound must be reviewed.

LT3045 MSE pin map includes all three IN pins and both OUT pins; EP13=GND.
SET49.9k ->4.990V and52k ->5.200V at100uA. Current limit499ohm ->~300mA.
PG divider150k/10k ->4.80V;158k/10k ->5.04V. OUTS Kelvin to output capacitor.
At0.20A and0.12A loads, LDO dissipation is approximately0.239W and0.118W.
These use nominal rails and exclude quiescent current. PCB thermal validation
and effective output capacitance are still required.

## Negative conversion

LT8330ES6#TRMPBF uses a real two-inductor inverting/Cuk topology:
VIN->L301->SW_NEG->C410->NEG_X->L302->negative OUT. Diode D301 anode=NEG_X,
cathode=GND. Independent10uH inductors (not unspecified coupled pinouts);
1uF/50V transfer capacitor must tolerate VIN+|Vout| and ripple current.
FBX=-0.8V, divider1M/147k gives about-6.242V. Feedforward4.7pF follows the
vendor topology. Negative continuous design budget is0.12A. This is not the
1A switch-current specification misrepresented as1A output capability.

For VIN8–15V, abs(Vout)=6.242V, diode0.5V, f>=1.8MHz design assumption,
L>=8uH, duty=(6.242+.5)/(VIN+6.242+.5), the approximate combined-switch peak
current at0.12A output is below0.6A (efficiency and ripple must be rechecked
with the actual inductor and PCB). Vsw ideal<22V at15V input; ringing and
surge remain unqualified. LT8330's 60V switch rating is not input immunity.

LT3094 MSE EP13=IN (-6V2_PRE), NOT GND. EN tied IN, unused VIOC open.
SET52k ->-5.2V, ILIM15k ->250mA. PG158k/10k ->about-5.04V. Two22uF output
capacitors must retain at least10uF effective combined. Dissipation at0.12A
is approximately(6.242-5.2)*.12=0.125W plus quiescent current.

ADR4525BRZ SO8:VIN2 GND4 VOUT6; pin8 DNC,1/3/5/7 NIC. Source from+5V0_DAC;
VREF_2V5 feeds four DAC external reference inputs. Disable each DAC's internal
reference as required by the verified register/startup sequence; do not assume
multiple enabled internal voltage sources can be paralleled.

## DAC load and rail margin

AD3542R Rev.C specifies digital dynamic DVDD up to40mA/device at its test mode,
AVDD up to28.5mA/device; output-stage currents are load dependent and some
published quiescent figures are typical, not guaranteed maxima. Four-DAC logic
is allocated0.30A total, +5V0 allocates0.20A, PVDD/PVSS each0.12A. No50ohm
terminated output-drive capability is claimed. Additional ADC/PHY loads must
be budgeted before adding them, not silently consume reserved power.

With +/-1% SET current and0.1% SET resistance, the nominal +/-5.2V rails each
reach about5.257V; summed span~10.514V stays below the10.6V recommended DAC
span in the static calculation. Startup overshoot and regulator accuracy over
temperature must still be measured; a nominal calculation is not a rail clamp.

## Primary sources
- AP63200/1/3/5 DS41326 Rev3-2:https://www.diodes.com/assets/Datasheets/AP63200-AP63201-AP63203-AP63205.pdf
- LT3045 RevD:https://www.analog.com/media/en/technical-documentation/data-sheets/lt3045.pdf
- LT3094 RevB:https://www.analog.com/media/en/technical-documentation/data-sheets/lt3094.pdf
- LT8330 RevD:https://www.analog.com/media/en/technical-documentation/data-sheets/lt8330.pdf
- ADR45xx RevG:https://www.analog.com/media/en/technical-documentation/data-sheets/ADR4520_4525_4530_4533_4540_4550.pdf
- AD3542R RevC:https://www.analog.com/media/en/technical-documentation/data-sheets/ad3542r.pdf

All native schematics remain NON-RELEASE until exact components, protection,
layout, transient/thermal, power-off backfeed and physical DUT safety pass review.

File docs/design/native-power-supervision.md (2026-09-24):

# Native power supervision — not complete DUT safety

The power stage now uses real TPS3808G01 supervisors for1V8,3V3 and VREF,
LT3045/LT3094 PG signals, and an AON-powered TLV1701 negative-rail detector.
No interface connector is substituted for a power monitor.

TPS3808 DBV pins: RESET1 GND2 MR3 CT4 SENSE5 VDD6. CT open gives20ms nominal
release delay. Dividers32.8k/10k,67.3k/10k,49.9k/10k give thresholds1.7334V,
3.13065V,2.42595V. Outputs are open drain wired together at RAILS_OK.
Positive analog PG and independent negative sense are ANDed with INPUT_OK,
then applied to U401 MR, so analog faults also restart the release delay.

Negative detector: NEG_FOLD=.75*VREF+.25*PVSS. Compare against VREF/4.
At2.5V reference, nominal trip is near-5.0V, so missing PVSS forces fault even
if an unpowered regulator's PG output floats. The1M feedback adds hysteresis;
Schottky clamps limit startup negative/positive excursions at the comparator.
Divider/offset/leakage/hysteresis and partial-power behavior require bench review.
Reference loss is separately caught by U403; NEG_VALID alone is not a valid signal.

SN74LVC1G74 DCT latch: CLK1 D2 QN3 GND4 Q5 CLR6 PRE7 VCC8.
RAILS_OK low asynchronously clears Q. A new HIL_ARM rising edge AFTER power
qualification sets Q. Restored rails do not automatically re-arm a previously
high HIL_ARM. HIL_ARM has100k pulldown. SN74LVC1G11 output supplied from1V8_D
combines RAILS_OK,ARM_LATCH,INPUT_OK and drives DAC_RESET_N at1.8V, with10k
hardware default pulldown. Inputs tolerate the3.3V AON-domain control levels.

HIL_FAULT_N is an open-drain POWER diagnostic through SN74LVC1G07. Configure
and verify a HOST-side pull-up; no expansion-board pull-up should back-power
an unpowered host. It is not a combined certified STO/encoder/watchdog status.

HIL_WDI currently terminates at TP401 ONLY. This power-phase deliverable DOES
NOT implement missing-heartbeat detection, physical analog-output disconnect
or DUT gate-driver inhibition. TPS3431 was not inserted merely as a placeholder:
its programmable minimum interval is about63ms, not the microsecond HIL loop
loss limit. A separately specified watchdog/inhibit circuit remains required.
DAC RESET does not equal zero current or a safe analog voltage. Do not energize
DUT MOSFETs or claim physical current-loop qualification from this schematic.

Sources:
- https://www.ti.com/lit/ds/symlink/tps3808.pdf
- https://www.ti.com/lit/ds/symlink/tlv1701.pdf
- https://www.ti.com/lit/ds/symlink/sn74lvc1g74.pdf
- https://www.ti.com/lit/ds/symlink/sn74lvc1g11.pdf
- https://www.ti.com/lit/ds/symlink/sn74lvc1g07.pdf
- https://www.ti.com/lit/ds/symlink/tps3431.pdf

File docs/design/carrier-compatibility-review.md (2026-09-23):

# PR #16 续作：单 SoC 双载板兼容审查

## 架构边界不变

一颗 ZU2CG 承担 Plant 与实时 I/O；AXU2CGB 开发板和市售 SoM 是替代载体。
自研板不增加 XC7A35T、另一块 FPGA 模块、配置 Flash、本地 FPGA JTAG/XO 或核心电源。
Rev.A 原工程只在 `archive/revA/snapshot` 保留，活动工程为 `hardware/revB`。

本轮没有新增 ADC、PHY、PMIC 或安全功能级“占位芯片”。当前图纸保留明确的外部
电源、安全、ADC 与 PHY 集成接口，不宣称这些真实电路已设计完毕。

## 两种载板现在如何共用设计

| 项目 | 原版 AXU2CGB | 市售 ZU2CG SoM |
|---|---|---|
| 物理来源 | 已转录的原版 J12/J15 | 必须选定厂商、型号、硬件版本 |
| 当前状态 | MAPPING_CANDIDATE | UNBOUND / BLOCKED_VENDOR_BINDING |
| 功能分配 | J12 32/34、J15 32/34 | 绑定后使用同一 64-net I/O 契约 |
| 原理图位号 | J12、J15 保留 | J100 起独立编号，厂商原编号另存 |
| 图纸组织 | 保留现有双接口页 | 每个连接器独立页，A3/A2/A1 自动选择 |
| 电源触点 | 全部 NC | I/O 审阅图仍为 NC；厂商供电另行设计 |
| Bank 电压 | J12 1.8 V；J15 3.3 V | 必须真实匹配；不支持用 CSV 别名冒充电平转换 |
| 公共 DAC 电路 | 复用 | 复用，不复制第二套逻辑 |
| 打板状态 | BLOCKED | BLOCKED |

`carrier_references.json` 为连接器名称与原理图位号对照；`derived_pin_map.csv`
同时给出物理 connector/pin、schematic_ref、SoC ball、HDL port、方向和电压制式。
这只是直连 I/O 预览，不是 Vivado 已验证的时序约束。

SoM 审阅模板目前支持至多 8 个连接器；图幅无法容纳时明确报错，不静默截断。
原理图连接器符号是**已购买 HOST 的电气边界模型**，不是自研板新增的计算器件。
不同模块的机械连接器、供电、启动和 pinout 不宣称兼容。

## 本轮复现并修复的问题

1. SoM 连接器叫 J1/J2/J3 时，会覆盖公共电源、安全或外设接口的位号。
   现在独立分配 J100+，并在生成器遇到重复位号时直接失败。
2. 第三个连接器或 160-pin 连接器会被画到 A3 图幅之外。
   现在分别分页及选择图幅，保留完整 pin-number 映射。
3. SoM 输出仍残留“ORIGINAL AXU2CGB”说明。
   现在显示实际绑定的 vendor/module/revision。
4. 物理表的未知 contact kind、pin 0、同 Bank 不同电压未被拦截。
   即使摘要值重新计算正确，这些不合法绑定也必须失败。
5. 旧网表检查只核对生成器自己的 expected_connections，遗漏了部分 DAC GND、
   DNC 和缺失反馈节点；两个缺失节点可能因 None == None 被视为相连。
   现在独立检查 DAC 全部已定义电源/控制/反馈网络和全部未连接脚。
6. 公共 BOM 混入 AXU2CGB 专属连接器。
   现在按 common/carrier 分离，并从实际原理图实例导出逐位号 generated_bom.csv。

## 验证分层

- 单元/变异回归：原有 22 项，加本轮 15 项；涵盖拒绝错误绑定与错误网表。
- 原 Notion verification-sync 的 15 项测试保持不变。
- AXU2CGB：真实 KiCad XML 网表、独立载板/DAC 对照、JSON ERC、PDF 导出。
- SoM：真实生产 profile 仍阻止生成；另外用明确标记的 SYNTHETIC_TEST_ONLY
  三连接器和 160-pin 测试数据运行原生 KiCad 网表/ERC/导出。
- Synthetic SoM PASS 仅证明生成与检查工具兼容不同连接器结构，**不等于某款核心板兼容通过**。
- 所有新硬件门禁保持 NOT_RUN；layout_allowed=false。没有继承 Rev.A ERC 或合并状态。

最终 exact-SHA CI 结果在 PR #16 验证评论中记录，避免在本文写入会自行失效的提交号。

## 后续仍需完成的真实电路

AXU2CGB 板版本签核、板载 I/O 电源、掉电反灌/输出使能、独立 inhibit 和模拟安全输出、
ADC/PHY、DAC CFB/负载/封装、Vivado I/O DRC/时序及 FOC 实测。SoM 另需厂商模块
资料与供电/启动/电压转换的具体电路。上述未闭合前不进入 PCB layout。

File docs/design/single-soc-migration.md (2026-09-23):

# Rev.A → Rev.B：单 SoC 架构迁移

## 保留与删除

历史快照：`archive/revA/snapshot/`，基线 `dbd0d32a030bcda0427fec31894c01db29717d8a`。

| 原设计 | 新处理 |
|---|---|
| XC7A35T Local FPGA、FGG484 ball plan | 从活动设计移除；历史可追溯 |
| Local FPGA QSPI、JTAG、XO、1.0V 核心电源 | 从活动设计移除 |
| HIL-Link 双向 DDR/CRC/链路调度 | 不再是物理板间接口；模块间连接在同一 ZU2CG PL 内实现 |
| AXU2CGB J12 物理 ball/pin 信息 | 保留并核对；增加 J15；不与功能映射混写 |
| ADP5054/ADM1186 等本地 FPGA 电源树 | 不自动沿用；按新的 I/O 供电与安全需求重新设计 |
| LT3045/LT3094/LTC7149/ADR4525 电路研究 | 历史和候选 BOM 保留；不能把旧参数当成新电源验证完成 |
| AD3542R / 输出范围 / 参考 / CFB | 在共同 I/O 设计中保留候选；模拟稳定性和封装仍待审查 |
| Plant/传感器/校准/provider 边界 | 保留；ADC/DAC 类型不进入 Plant 方程 |

## 两种载板的边界

AXU2CGB 扩展板使用原版 J12/J15，电源触点全部 NC。使用经过转录的固定 SoC ball，仍需对用户手上实物版本和主机工程核对。J15 的公开手册给出 Bank25/26 组；本版本不臆造每个 ball 的独立 Bank 归属。

SoM 底板与扩展板共享逻辑契约，但**不共享未经证实的连接器 pinout**。必须在选定模块后录入厂商、版本、供电/启动要求、可用 PL I/O、Bank VCCO、时钟脚和物理映射。只有 HP/1.8V I/O 的核心板不能直接连接 3.3V 数字前端；需有实际且经过审查的转换电路，再扩展对应适配实现，不能用 CSV 别名假装转换。

## 门禁替换

- `xc7a35t_pinplan` → SUPERSEDED；替换为 `carrier_pinout_review` 和 `vivado_io_drc`。
- `hil_link_crosscheck` → SUPERSEDED；替换为 `carrier_schematic_xdc_crosscheck`。
- Rev.A ERC → SUPERSEDED；Rev.B 原生工程重新运行。
- 不用合并 PR/关闭 Issue 表示实机 PASS。

新门禁均从 NOT_RUN 开始。允许检查“未绑定 SoM 的 schema 正确”，不允许把它表述为“核心板物理兼容通过”。

## 当前原理图为何使用明确接口

原工程存在功能级符号、未冻结的电源参数和未知安全/封装细节。迁移不复制这些未完成部分并重命名为已完成电路。

新原生 KiCad 工程包含直接载板接口、完整的 8-AO DAC 电气候选以及明确的外部稳压供电/独立安全/ADC与PHY边界。它支持分阶段审阅和实验室连接规划，不授权直接打板或接入功率级。下一轮应在同一接口契约下完成板载 I/O 电源、独立 inhibit/safe-output 网络、ADC AFE 和数字 PHY，再进行硬件评审。

## 供应与安全要求

1. AXU 与 I/O 板任意上/掉电顺序，既查电源针也查信号针反灌。
2. I/O 没供电、SoC 未配置、时钟停止、模型超时，DUT 功率级保持硬件禁止。
3. WDI 必须证明实时链路取得进展，不能由无关自由运行定时器持续喂狗。
4. DAC RESET 与安全电流反馈不同：中点偏置、钳位和模拟开关安全状态按 DUT profile 定义。
5. `<1us` 和 `5ns` 为目标，分别是路径时延与时间戳分辨率，不是已测性能。

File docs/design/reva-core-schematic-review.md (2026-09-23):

# Rev.A HIL-Link / Local FPGA / DAC schematic review

Status: **electrical hierarchy complete; KiCad ERC 0 errors / 0 warnings; PCB layout still blocked**.

## 04_AXU_HIL_LINK

Implemented from `docs/icd/j12-hil-link.csv`:

- J10 mirrors AXU2CGB J12 2×20 pinout.
- Bank66 interface is treated as 1.8 V logic.
- AXU board 5 V / 3.3 V connector power pins are explicit NC.
- ZU2CG → Local FPGA: `HL_TX[7:0]`, `HL_TX_CLK`, `HL_SYNC`, safety/control inputs.
- Local FPGA → ZU2CG: `HL_RX[7:0]`, `HL_RX_CLK`, `HL_IRQ`.
- ServoHIL-source outputs use 33 Ω starting source-series resistors.
- unused GC/debug/spare pins are explicit NC rather than floating named nets.

The 33 Ω value is a signal-integrity starting point, not a final impedance result.

## 05_IO_FPGA

Implemented:

- U10 `XC7A35T-1FGG484I FUNCTIONAL_PRELAYOUT`.
- 1V0 / 1V8 / 3V3 rail contracts.
- complete logical HIL-Link port set.
- complete DAC serializer/control port set.
- W25Q128-class QSPI configuration flash.
- 100 MHz / 1.8 V oscillator.
- JTAG boundary.
- configuration pull-ups and representative bulk decoupling.
- independent watchdog and hardware safe-release chain.
- `DAC_RESET_N` has a 100 kΩ default-safe pull-down.

Safety qualification is intentionally outside the FPGA application logic:

```text
FPGA_DONE
    AND SEQ_DONE
    AND external watchdog OK
        -> SAFE_RELEASE_3V3
        -> 3.3V / 1.8V safety translation
        -> DAC_RESET_N
```

Exact FGG484 balls are still **UNASSIGNED**. KiCad must not become the source of PACKAGE_PIN truth; Vivado I/O Planner is.

## 06 / 07 AD3542R

Four 28-pin electrical instances are implemented:

| Ref | Outputs |
|---|---|
| U20 | AO0 Ia / AO1 Ib |
| U21 | AO2 Ic / AO3 Vbus |
| U22 | AO4 Torque / AO5 Temperature |
| U23 | AO6 AUX0 / AO7 AUX1 |

Rev.A fixed electrical contract:

- DVDD = 1.8 V
- VLOGIC = 1.8 V
- AVDD = +5.0 V
- PVDD = +5.2 V
- PVSS = -5.2 V
- VREF = 2.5 V external reference
- ±5 V output mode uses `RFB2_y` feedback
- `RFB1_y` and `RFB4_y` are explicit NC
- CFB uses DNP NP0/C0G tuning footprints
- AO source resistance starts at 52.3 Ω and remains tunable
- ALERT pins have 1.8 V pull-ups
- shared `DAC_LDAC_N` / `DAC_RESET_N` / `DAC_SCLK`
- independent chip select and dual-SPI data lanes

J20 now provides the explicit DUT analog-output boundary:

```text
AO0..AO7 + GND + GND
```

Connector family/footprint remains a mechanical-layout decision.

## FPGA constraint artifacts

`hardware/fpga/revA/pin_plan.csv` now includes HIL-Link, DAC, QSPI and watchdog-service signals.

All FGG484 package-pin fields deliberately remain:

```text
package_pin = empty
status = UNASSIGNED
```

Templates:

- `hil_link_ports.xdc.tmpl`
- `dac_ports.xdc.tmpl`

The HIL template establishes 100 MHz source-synchronous intent; exact I/O delays wait for package pin selection and PCB flight time.

The DAC template constrains the 1.8 V interface and uses the AD3542R 66 MHz maximum SCLK basis.

## Validation

Latest full-hierarchy CI:

```text
KiCad CLI             10.0.6
structure check       PASS
layout gate           PASS (layout disabled)
POWER contract        PASS
core contract         PASS
hierarchy parse       PASS
ERC errors            0
ERC warnings          0
schematic PDF export  PASS
```

## Remaining freeze work before PCB layout

- [ ] Vivado/XPE power estimates
- [ ] ADP5054 magnetics / compensation / MOSFET / thermal freeze
- [ ] LTC7149 negative-rail transient/stability freeze
- [ ] full verified package symbols / footprints where still pre-layout
- [ ] XC7A35T FGG484 I/O Planner assignment
- [ ] reviewed PACKAGE_PIN XDC
- [ ] J12 ↔ schematic ↔ XDC sign-off
- [ ] AD3542R footprint / CFB / cable-load / source-resistor analog review
- [ ] only then set `layout_allowed: true`

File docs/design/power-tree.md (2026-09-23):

# Rev.A power architecture

Status: **real schematic populated; switching-stage values remain PRELIM until freeze gates pass**.

## Topology

```text
9-15 V input
  -> SMBJ16A-class TVS
  -> TPS259474L eFuse
       UVLO ~8.0 V
       OVLO ~15.9 V
       current limit ~4 A
       controlled dV/dt
       PG -> 3V3_AON domain
  -> 12V_PROT
       |
       +-> TPS70933 -> 3V3_AON
       |
       +-> ADP5054
       |     CH1 -> 1V0_FPGA
       |       external low-side NFET required
       |     CH3 -> 1V8_D
       |     CH4 -> 3V3_D
       |     CH2 -> 6V0_PRE
       |       external low-side NFET required
       |
       +-> LTC7149 -> -6V0_PRE

6V0_PRE
  +-> LT3045 -> +5V0_DAC
  +-> LT3045 -> +5V2_PVDD

-6V0_PRE -> LT3094 -> -5V2_PVSS
+5V0_DAC -> ADR4525 -> VREF_2V5
```

## Sequencing

A TPS70933 3.3 V always-on rail powers the sequencer and safety logic.

`EFUSE_PG` is RC-delayed and passed through a Schmitt input before driving the ADM1186 `UP` input. This is intentional: ADM1186 `UP` must receive a valid rising edge after its supply is established rather than being hard-wired high at power-up.

Sequence intent:

```text
1V0_FPGA
  -> 1V8_D
  -> 3V3_D
  -> 6V0_PRE
  -> ANALOG_EN
  -> +5V0_DAC / +5V2_PVDD / -6V0_PRE path
  -> -5V2_PVSS
```

The current schematic maps ADM1186 outputs as:

| Sequencer output | ADP5054 channel | Rail |
|---|---|---|
| OUT1 | CH1 | 1V0_FPGA |
| OUT2 | CH3 | 1V8_D |
| OUT3 | CH4 | 3V3_D |
| OUT4 | CH2 | 6V0_PRE |

`ANALOG_EN` is derived from the sequencer PWRGD path and enables the low-noise analog supply chain.

## Preliminary rail budget

| Rail | Main load | Preliminary budget | Status |
|---|---|---:|---|
| 1V0_FPGA | XC7A35T VCCINT/VCCBRAM | 1.5 A | pending XPE |
| 1V8_D | VCCAUX/VCCO + HIL-Link + DAC logic | 1.2 A | pending XPE |
| 3V3_D | config flash / Bank0 / debug | 1.2 A | pending pin plan |
| 6V0_PRE | positive analog preregulator | 0.8 A | pending DAC load |
| +5V0_DAC | DAC AVDD + reference | 0.25 A | pending model |
| +5V2_PVDD | DAC positive output stage | 0.25 A + load | pending load |
| -6V0_PRE | LT3094 input | 0.25 A class | pending DAC load |
| -5V2_PVSS | DAC negative output stage | 0.25 A + load | pending load |

## Values currently placed in the schematic

These values are engineering starting points, not PCB-freeze values:

- TPS259474L UV/OV divider: 680 kΩ / 60.4 kΩ / 60.4 kΩ.
- TPS259474L RILM: 825 Ω, approximately 4 A class.
- TPS259474L dV/dt capacitor: 3.3 nF.
- ADP5054 oscillator: 32.4 kΩ RT, 600 kHz class.
- ADP5054 CH1/CH2 low-side current-limit programming: 47 kΩ class.
- ADP5054 output inductors: 1.0 / 4.7 / 3.3 / 4.7 µH for CH1/CH2/CH3/CH4, all **PRELIM**.
- ADP5054 compensation: 10 kΩ + 2.2 nF starting network, **PRELIM**.
- LT3045 SET: 49.9 kΩ for +5.0 V and 52.0 kΩ for +5.2 V.
- LTC7149 SET: 120 kΩ for -6 V class, with demo-derived magnetics/compensation marked **PRELIM**.
- LT3094 SET: 52.0 kΩ for -5.2 V; ILIM 15 kΩ for ~250 mA class.
- ADR4525 provides VREF_2V5.

## Important ADP5054 implementation detail

ADP5054 Channels 1 and 2 integrate the high-side FET but use **external low-side NFETs** driven from DL1/DL2. Channels 3 and 4 integrate both high- and low-side switches. The Rev.A schematic explicitly includes Q1/Q2; their exact part number remains a freeze item.

## Not frozen yet

Do not authorize PCB placement based on the current power-stage passives.

The following still require review:

- Vivado/XPE current estimates for the XC7A35T;
- ADP5054 inductor saturation/ripple design;
- CH1/CH2 low-side MOSFET selection and thermal loss;
- output capacitance after DC-bias derating;
- loop compensation/stability;
- 9-15 V min/max duty-cycle and timing margins;
- load-step response;
- startup monotonicity;
- regulator junction temperature;
- LTC7149 negative-rail transient/stability behavior.

Until those close, `power_tree_frozen` in `layout_gate.yaml` remains false.

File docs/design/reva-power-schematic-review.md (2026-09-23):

# Rev.A power schematic implementation review

Status: **POWER sheets populated; ERC/freeze gates still open**.

This document records what is intentionally real, what is preliminary, and what must be verified before layout.

## 01_POWER_ENTRY

Implemented:

- J1 9-15 V DC input.
- SMBJ16A-class input TVS.
- input bulk + ceramic decoupling.
- TPS259474L eFuse.
- UVLO/OVLO divider.
- ~4 A current-limit programming.
- dV/dt capacitor.
- fault timer capacitor.
- programmable PGTH divider.
- 3V3_AON pull-up for `EFUSE_PG`.
- 12V_PROT output decoupling.

Current candidate thresholds:

```text
UVLO ≈ 8.0 V
OVLO ≈ 15.9 V
ILIM ≈ 4 A class
```

The exact surge profile and TVS energy rating remain an input-interface verification item.

## 02_ANALOG_POWER

Implemented:

- LT3045 +5V0_DAC post-regulator.
- LT3045 +5V2_PVDD post-regulator.
- LTC7149 negative preregulator to -6V0_PRE.
- LT3094 negative post-regulator to -5V2_PVSS.
- ADR4525 VREF_2V5.
- input/output and SET capacitors.
- LT3045 PG left unused while PGFB is tied to input per the device guidance.
- LT3045 and LT3094 exposed-pad electrical connections are represented.
- LT3094 unused PG/VIOC handling is explicit.

The LTC7149 switching components are deliberately marked PRELIM.

## 03_DIGITAL_POWER

Implemented:

- TPS70933 3V3_AON supply.
- delayed `SEQ_START` from `EFUSE_PG`.
- ADM1186-1 rail sequencing/monitoring.
- explicit pull-ups for open-drain sequencer outputs.
- ADP5054 channel assignment.
- external low-side Q1/Q2 for ADP5054 CH1/CH2.
- RT programming and VDD/VREG decoupling.
- CFG12/CFG34 and SYNC/MODE baseline states.
- four bootstrap capacitors.
- four feedback-divider networks.
- four compensation starting networks.
- CH1/CH2 DL current-limit programming.
- per-channel input bypass and output bulk capacitors.

### ADP5054 symbol status

The schematic currently uses a **functional pre-layout symbol** containing the pins required to review the power topology. It intentionally has no footprint assignment.

Before `fpga_pinplan_frozen` / `power_tree_frozen` allow layout, replace it with a complete verified 48-lead LFCSP symbol including every duplicated PVIN/SW/PGND pin and exposed pad, then cross-check against the vendor pin table.

This is intentional: a fake complete footprint mapping is worse than an explicit pre-layout functional symbol.

## Safety / sequencing rule

The power tree alone does not release the DAC path. Later core sheets must still enforce:

```text
DAC_RESET_N =
  FPGA_CONFIG_OK
  AND MANDATORY_POWER_GOOD
  AND HIL_LINK_WATCHDOG_OK
```

The default unpowered/unconfigured state remains SAFE.

## Exit requirements for the power phase

- [ ] KiCad CLI parses all Rev.A hierarchy sheets.
- [ ] KiCad ERC report generated and reviewed.
- [ ] no duplicate references across Rev.A hierarchy.
- [ ] power-schematic contract test passes.
- [ ] Vivado/XPE current budget imported.
- [ ] ADP5054 passives calculated/frozen.
- [ ] Q1/Q2 MOSFET selected and loss checked.
- [ ] LTC7149 negative-rail design verified.
- [ ] thermal budget reviewed.
- [ ] `power_tree_frozen` set true only in a dedicated reviewed change.

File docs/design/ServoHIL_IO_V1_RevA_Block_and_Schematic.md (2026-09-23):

# ServoHIL-I/O V1 Rev.A — detailed block and schematic review

This document complements the native KiCad hierarchy under `hardware/kicad/revA/`.

Scope remains frozen to:

```text
POWER -> HIL-Link -> Local FPGA -> 8ch fast DAC -> DUT Adapter
```

## 1. System partition

- AXU2CGB / ZU2CG owns inverter, PMSM, mechanics, gearbox and sensor plant models.
- Local I/O FPGA owns deterministic transport, edge timestamping, DAC serialization, trace FIFO and autonomous safe-state behavior.
- DUT Adapter owns controller-specific range scaling, clamp/protection and later physical fault insertion.
- Rev.A does not implement ADC, general DIO, encoder PHY, CAN/RS485 or FIU hardware.

## 2. POWER

Selected topology:

```text
9–15 V IN
  -> TVS
  -> TPS25947-class eFuse
  -> 12V_PROT
       -> ADP5054
            -> 1V0_FPGA
            -> 1V8_D
            -> 3V3_D
            -> 6V0_PRE
                 -> LT3045 -> +5V0_DAC
                 -> LT3045 -> +5V2_PVDD
       -> LTC7149 -> -6V0_PRE -> LT3094 -> -5V2_PVSS

+5V0_DAC -> ADR4525 -> VREF_2V5
```

A small 3V3_AON rail supplies the sequencer/supervisor path before the main FPGA rails are released.

Target power order:

1. 1V0
2. 1V8
3. 3V3
4. analog preregulator
5. positive/negative DAC rails

Final ADP5054 inductors, switching frequencies, compensation and capacitance are not frozen until Vivado/XPE current estimates and transient/thermal calculations are available.

## 3. HIL-Link

Boundary: AXU2CGB J12 / ZU2CG Bank66 / 1.8 V.

Electrical contract:

- LVCMOS18
- 100 MHz source-synchronous clock
- DDR data
- 8 bits each direction
- per-frame sequence and CRC
- dedicated safe/reset/heartbeat sideband
- source damping footprint on FPGA-driven groups

The raw link rate is 1.6 Gbit/s per direction.

Fast Plant-to-I/O frame:

```text
SEQ       16 bit
AO0..7   128 bit
FAST_DO   32 bit
CONTROL   16 bit
CRC16     16 bit
----------------
TOTAL    208 bit
```

At 1.6 Gbit/s this is about 130 ns serialization time.

The authoritative J12 pin assignment is `docs/icd/j12-hil-link.csv`. The schematic and Local-FPGA XDC must be cross-checked against that file.

## 4. Local I/O FPGA

Candidate device: `XC7A35T-1FGG484I`.

The device does **not** run the PMSM plant.

Initial bank intent:

- configuration/QSPI/debug: 3.3 V
- HIL-Link: 1.8 V
- AD3542R digital interface: 1.8 V
- future I/O banks remain reserved

Concrete FGG484 PACKAGE_PIN values remain unassigned until Vivado I/O Planner and DRC pass.
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

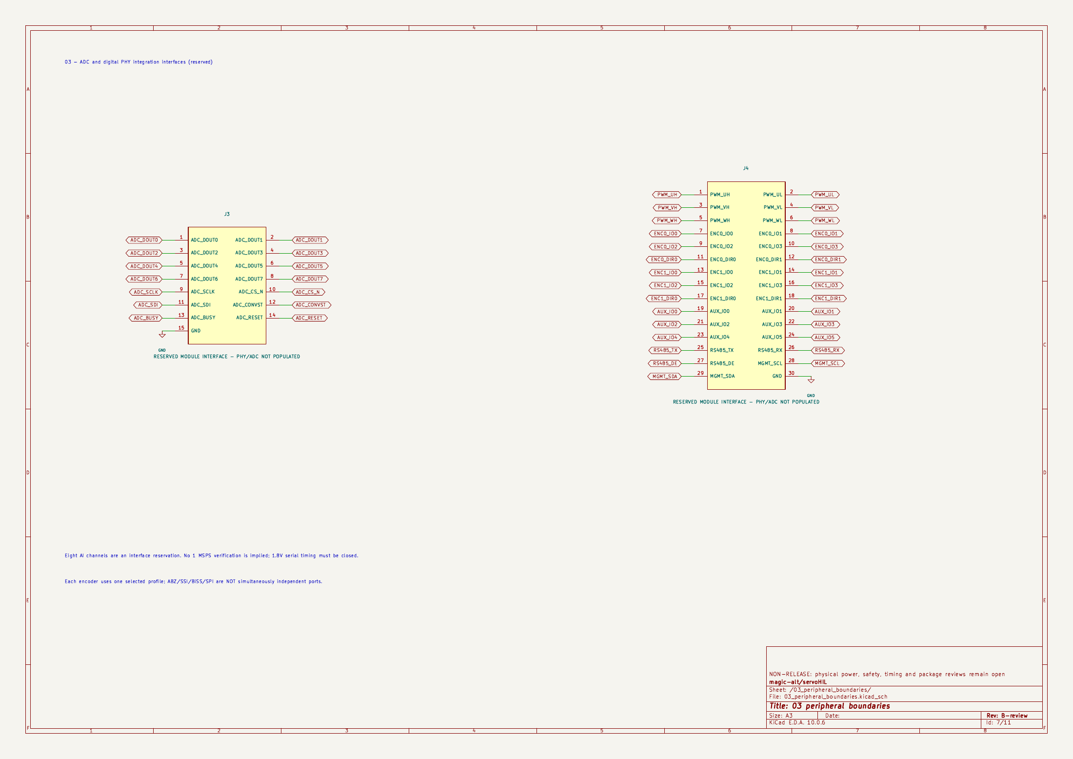
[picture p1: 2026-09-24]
docs/review/revb-readability/previews/page-07.png

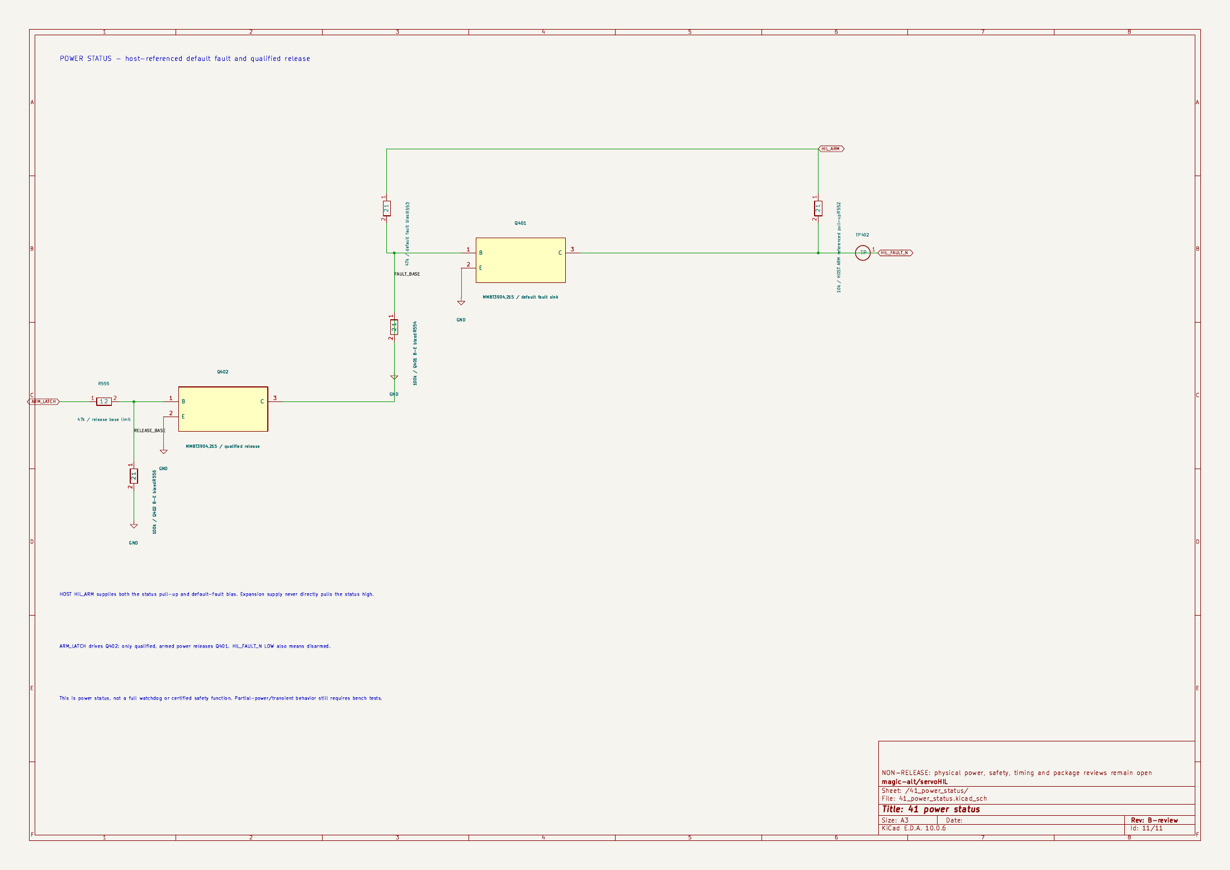
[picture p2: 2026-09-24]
docs/review/revb-readability/previews/page-11.png

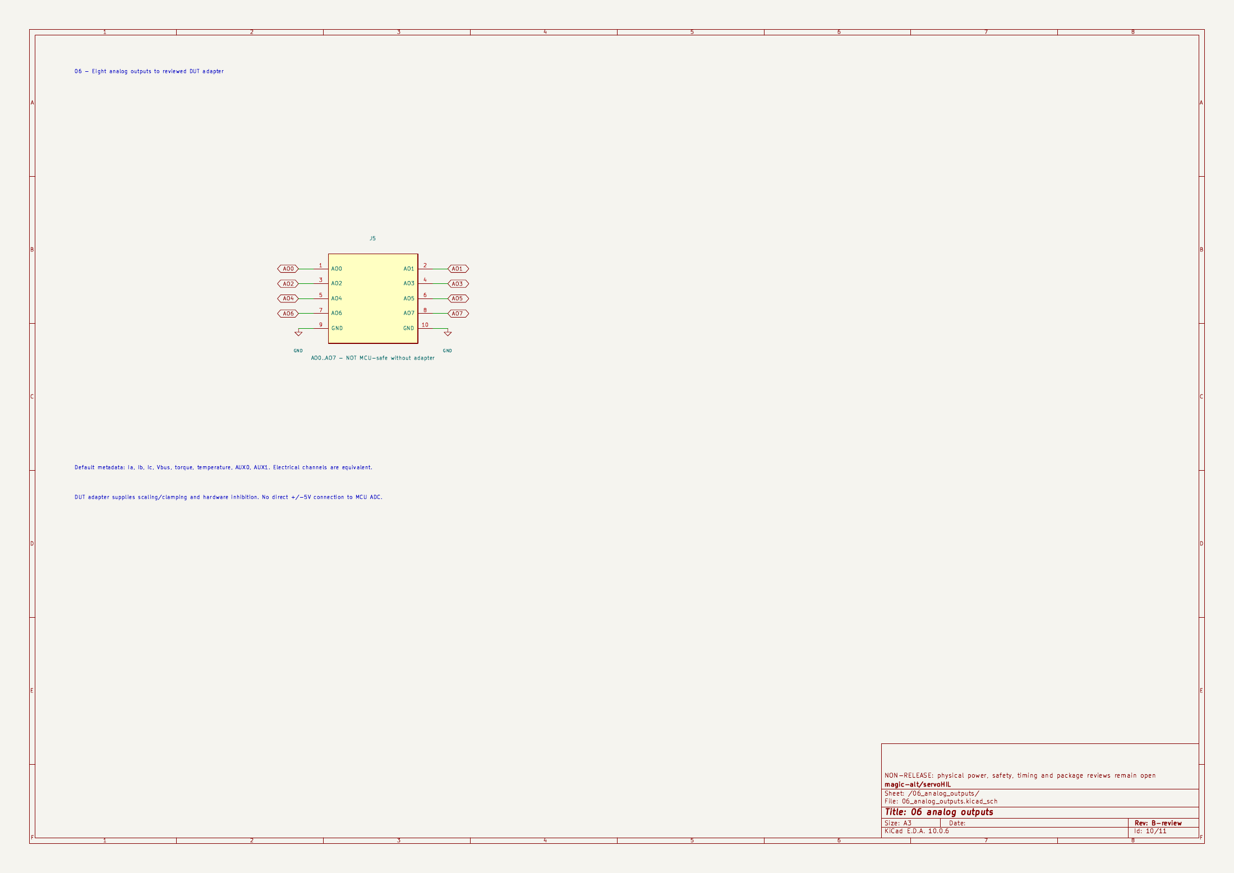
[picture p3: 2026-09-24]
docs/review/revb-readability/previews/page-10.png

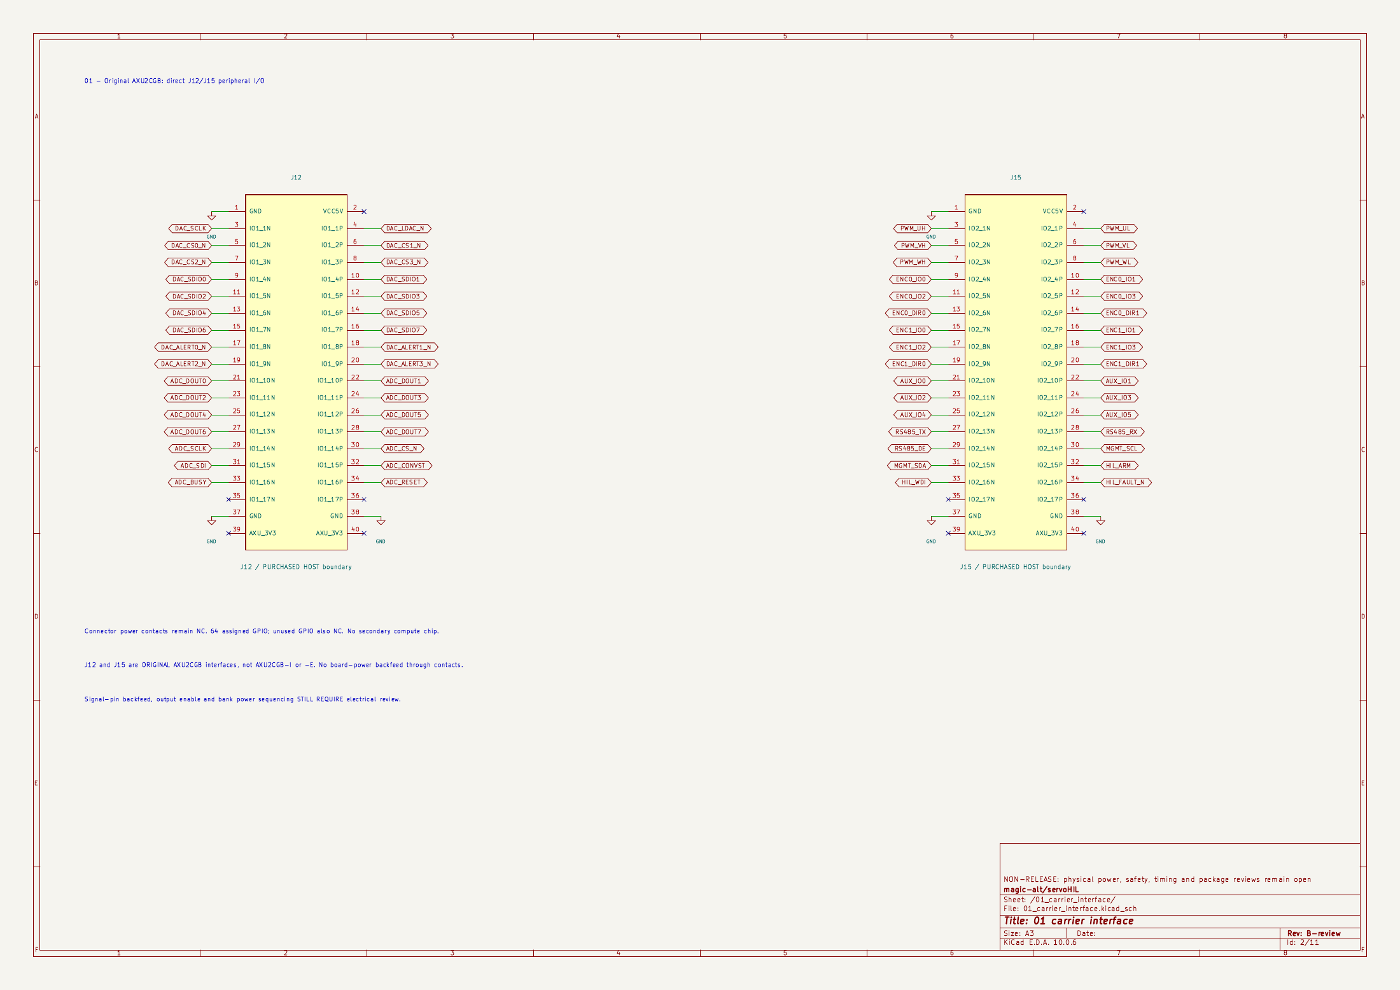
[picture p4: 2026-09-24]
docs/review/revb-readability/previews/page-02.png

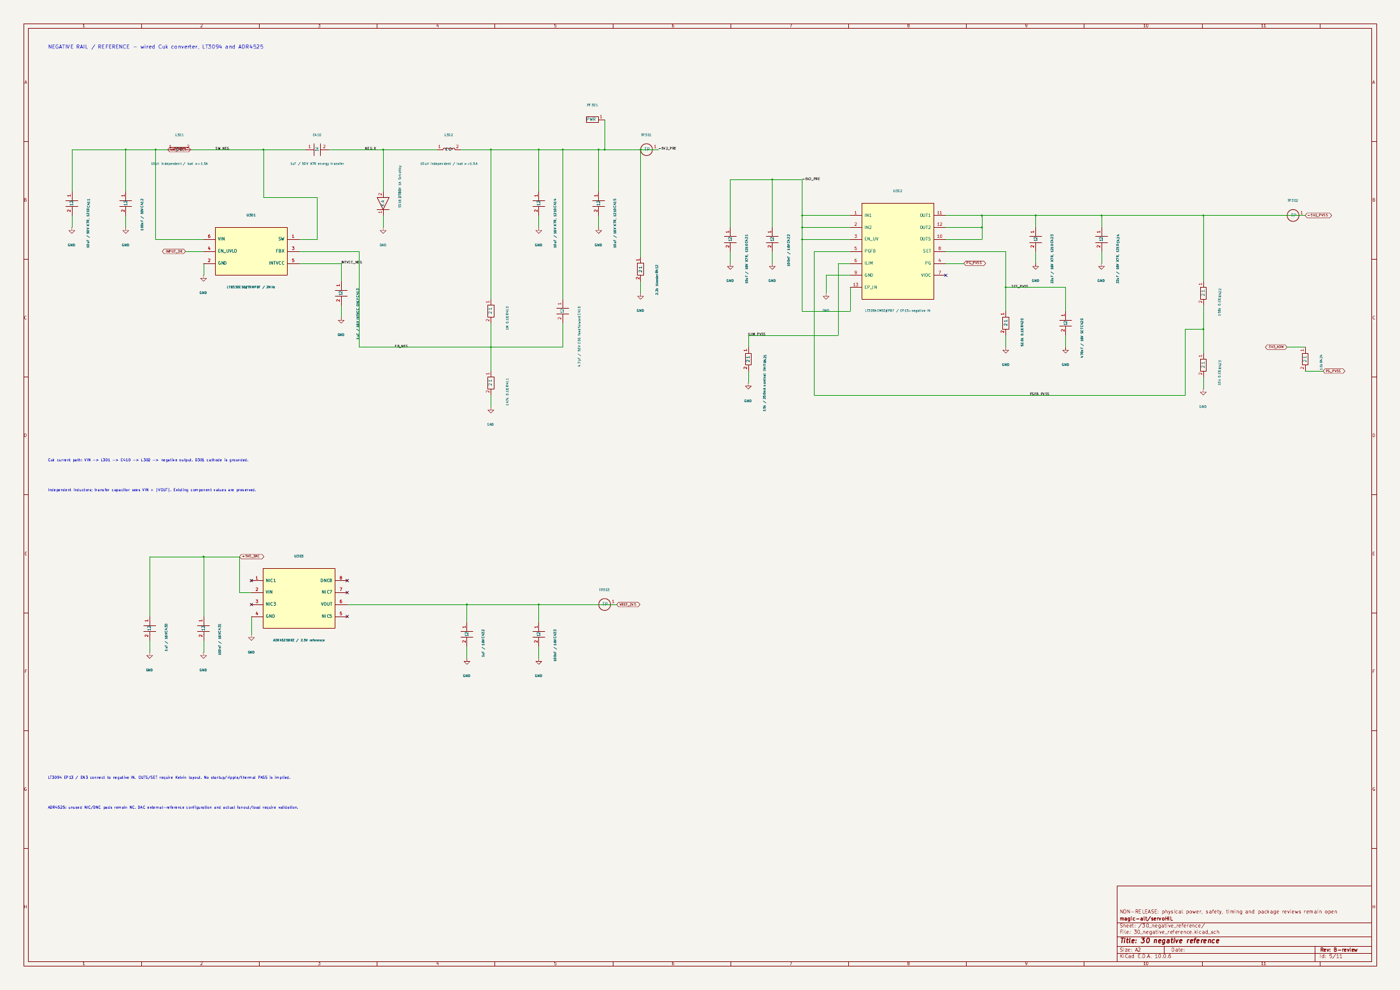
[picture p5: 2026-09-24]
docs/review/revb-readability/previews/page-05.png

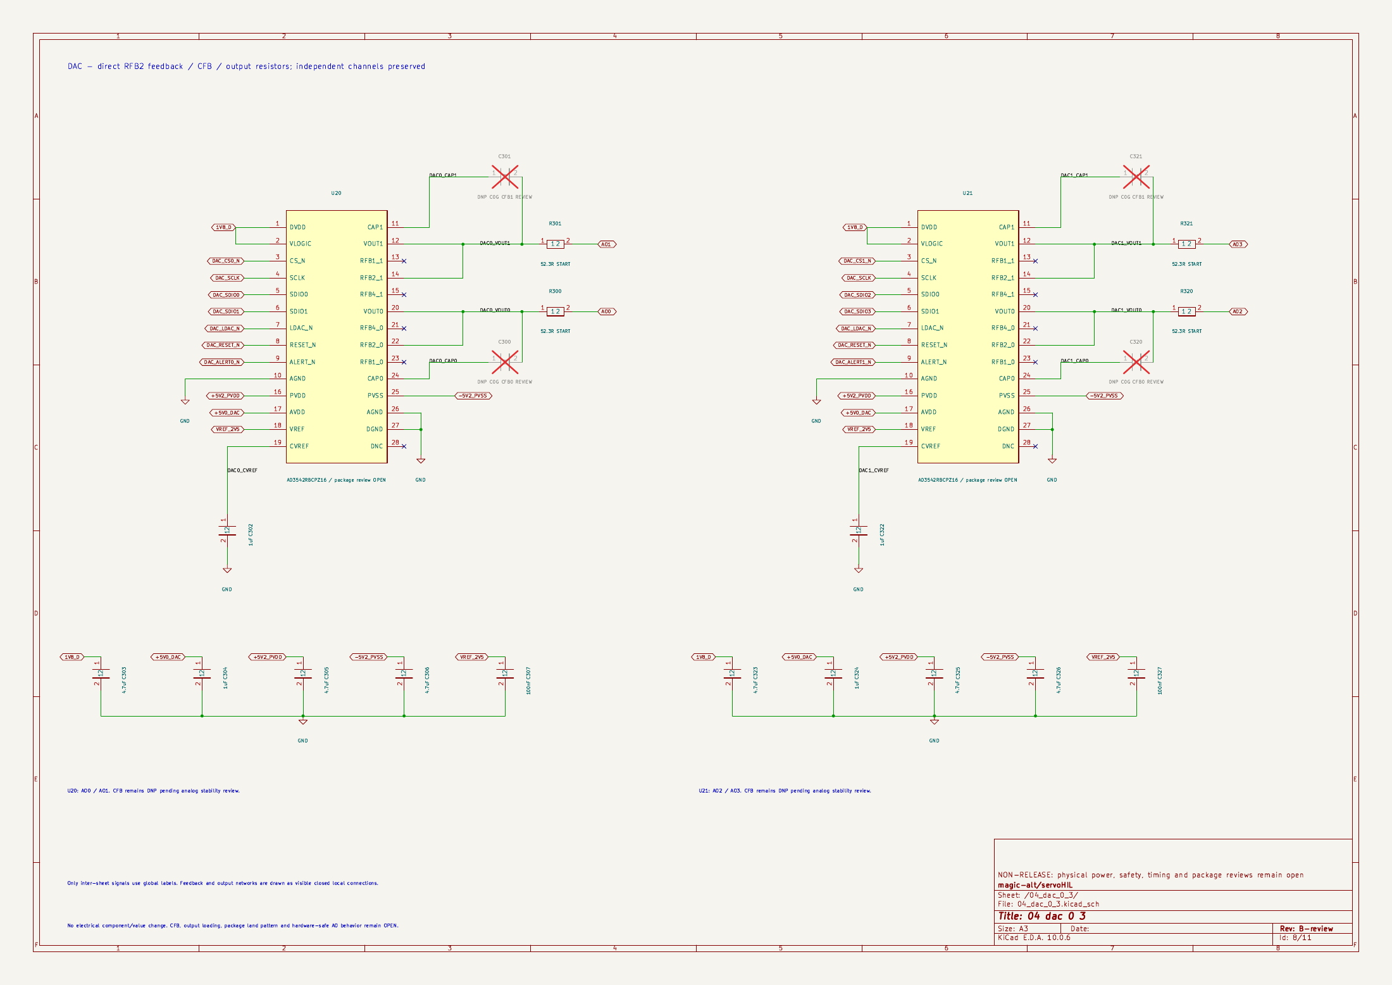
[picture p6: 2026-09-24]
docs/review/revb-readability/previews/page-08.png

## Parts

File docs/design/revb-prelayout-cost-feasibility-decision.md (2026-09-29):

# Rev.B Pre-Layout Cost / Feasibility Decision

> **Decision date:** 2026-09-29  
> **Scope:** personal single-axis servo / joint-module HIL before PCB Layout freeze  
> **Decision status:** **HOLD_FULL_8AO_LAYOUT — validate reduced-cost architecture first**  
> **Machine gates unchanged:** `layout_allowed=true`, `fabrication_allowed=false`, `release_allowed=false`.

This decision does not invalidate the current Rev.B schematic. The present 8-AO
AD3542R architecture remains the **full-performance reference configuration**.
However, it is no longer the recommended default population for a personal
prototype.

## 1. Why this review exists

The current costed BOM is approximately:

- one fully populated board: **CNY 4,085**
- four AD3542RBCPZ16 devices: **CNY 2,318 / board**
- AD7606C-16: **CNY 456 / board**
- two ADG5412F: **CNY 202 / board**

The four AD3542R devices alone are roughly 57% of the board component budget.
For a personal project, committing PCB Layout around mandatory eight-channel,
16-bit, 100-ns analog output before proving that all eight channels need that
latency/resolution is poor capital efficiency.

## 2. AD3542R is not technically wrong

ADI explicitly lists hardware-in-the-loop as an AD3542R application. The device
provides:

- dual channel;
- 12-bit or 16-bit variants;
- 16 MUPS fast-mode update capability;
- 100 ns large-signal settling to 0.1%;
- selectable 0–2.5 V, 0–5 V, 0–10 V, -5–+5 V and -2.5–+7.5 V ranges;
- 1.2/1.8 V compatible serial I/O.

Source:
https://www.analog.com/en/products/ad3542r.html

The current AD3542RBCPZ16 small-quantity DigiKey price is about USD 86.38 each.
The AD3542RBCPZ12-RL7 12-bit variant is about USD 45.10 each and uses the same
28-lead 4 mm x 4 mm LFCSP package family.

Sources:
https://www.digikey.com/en/products/detail/analog-devices-inc/AD3542RBCPZ16/16580691
https://www.digikey.com/en/products/detail/analog-devices-inc/AD3542RBCPZ12-RL7/16651465

The cost problem is therefore **channel count and specification level**, not an
obvious bad component choice.

## 3. Is there a direct non-ADI replacement?

There is no inexpensive, obvious pin-compatible non-ADI replacement matching the
full combination of:

- dual channel;
- 16-bit precision;
- direct bipolar output;
- approximately 100 ns settling;
- low-latency SPI;
- 1.8 V logic;
- compact package.

Functional alternatives exist, but each trades something.

### TI DAC80504 / DAC80508

DAC80504 provides four 16-bit buffered channels, 5 us settling, 0–5 V output,
1.7–5.5 V SPI and an internal reference.

Source:
https://www.ti.com/product/DAC80504

Current small-quantity DAC80504 pricing is about USD 28.76 for four channels.

This is attractive if Rev.B is narrowed to **actual DUT sensor-level unipolar
signals** rather than generic ±5 V outputs. It does not satisfy the current
1 us PWM-to-AO target.

### TI DAC81404 / DAC61404

DAC81404 is a four-channel 16-bit buffered high-voltage DAC. It directly supports
±5 V / ±10 V / ±20 V, has 1.7 V compatible SPI and an integrated reference.
Typical settling is on the order of several microseconds; for a 10 V span the
datasheet is approximately 8 us to ±2 LSB.

Sources:
https://www.ti.com/product/DAC81404
https://www.digikey.com/en/products/detail/texas-instruments/DAC81404RHBT/13562978

This is a strong functional non-ADI alternative when 8–10 us analog latency is
acceptable, but its high-voltage analog supply requirements imply a power-tree
redesign.

DAC61404 is the pin-compatible 12-bit family member.

Source:
https://www.ti.com/product/DAC61404

### TI DAC82001 / DAC8830

These are 16-bit single-channel approximately 1 us precision DACs. DAC82001 is
about USD 16.88 each at small quantity.

Sources:
https://www.ti.com/product/DAC82001
https://www.digikey.com/en/products/detail/texas-instruments/DAC82001DRXR/17394927

Four channels are substantially cheaper than the present four AD3542R devices,
but the parts are single-channel/unbuffered and require external output stages,
additional synchronization and likely digital-level adaptation. This increases
design risk and component count.

### TI DAC5672 / AD9767 class

TI DAC5672 is a dual 14-bit 275 MSPS current-output DAC and is documented by TI
as pin-compatible with AD9767. This proves that high-speed DAC alternatives are
not exclusive to ADI, but these parts use parallel digital interfaces and
current-output analog stages rather than the present AD3542R SPI / direct-voltage
architecture.

Source:
https://www.ti.com/product/DAC5672

AD9767 itself is a dual 14-bit 125 MSPS current-output device with roughly 35 ns
settling.

Source:
https://www.analog.com/en/products/ad9767.html

This class is more appropriate for a separate high-speed DAC module than as a
drop-in Rev.B replacement.

## 4. Requirement review: how many fast analog channels are really needed?

For a single-axis FOC HIL, the time-critical analog outputs are normally a subset
of:

- phase-current sensor A;
- phase-current sensor B;
- optional phase-current sensor C;
- DC-bus voltage or another fast protection/sensor channel.

Rotor position/speed should remain on the digital encoder path. Temperature,
torque, auxiliary sensors and configuration voltages generally do not require
100 ns settling.

Therefore **four fast AO channels are a better default architecture than eight**
unless a concrete DUT contract proves that >4 simultaneous sub-microsecond analog
signals are required.

The repository currently calls the provider `ad3542r_8ao_candidate`; the eight
channels have not been justified by a machine-readable minimum DUT signal set.

## 5. Cost options

Using the current Rev.B CNY planning model and current small-quantity public
prices:

| Option | Analog architecture | Estimated component BOM | Reduction vs current | Main trade-off |
|---|---|---:|---:|---|
| Full | 4 x AD3542R-16, 8 fast AO, AD7606C populated | ~CNY 4,085 | baseline | maximum capability / maximum cost |
| Same architecture, 12-bit | 4 x AD3542R-12 | ~CNY 2,977 | ~27% | lower DAC resolution, same eight channels |
| **Recommended Base-A** | **2 x AD3542R-12 = 4 fast AO; one ADG5412F; ADC retained** | **~CNY 2,270** | **~44%** | four fast AO instead of eight |
| **Recommended Base-B** | **Base-A plus AD7606C DNP for first prototype** | **~CNY 1,815** | **~56%** | no onboard 8-AI acquisition in initial build |
| Mid-speed redesign | 1 x DAC80504 + output/protection stage, 4 AO | ~CNY 1.9k–2.2k engineering estimate | ~46–54% | 5 us DAC, unipolar unless external level shift |
| Bipolar mid-speed redesign | 1 x DAC81404 + protection, 4 AO | ~CNY 2.0k class engineering estimate | ~50% | ~8 us at 10-V span; power-tree redesign |
| 1-us TI redesign | 4 x DAC82001 + buffers/protection | ~CNY 2.1k–2.4k engineering estimate | ~40–50% | more analog parts and synchronization complexity |

The redesign estimates are architecture budgets, not release BOM quotes.

## 6. Recommended implementation decision

### Decision A — do not freeze the current 8-AO full-population Layout

Keep the existing full schematic as the capability ceiling, but change the
prototype objective from “eight channels fully populated” to
**“four critical fast AO channels, optional expansion to eight.”**

Recommended PCB population strategy:

- U20/U21: populated by default;
- U22/U23: DNP by default, footprints/routing retained for later expansion;
- U601: populated for AO0..3;
- U602: DNP by default;
- AD7606C-16: optional first-spin DNP unless a defined closed-loop requirement
  needs onboard AI;
- keep the full connector/mechanical expansion path so the same PCB can later be
  upgraded without a new board spin.

### Decision B — default DAC grade should be selected by a resolution test

Start with AD3542R-12 only if its output quantization is demonstrably below the
DUT's relevant input-referred error/noise budget.

For reference:

- 12 bit over 10 V span: approximately 2.44 mV/LSB;
- 12 bit over 5 V span: approximately 1.22 mV/LSB;
- 16 bit over 10 V span: approximately 0.153 mV/LSB.

The HIL DAC range should be matched to the real sensor range instead of always
using ±5 V. If the DUT current-sense range is only 0–3.3 V or 0–5 V, a narrower
range materially improves effective resolution and may eliminate the need for a
bipolar architecture.

### Decision C — benchmark real timing before selecting a slower TI DAC

Before any PCB Layout freeze, measure:

`DUT PWM edge -> FPGA capture -> Plant result ready -> DAC output settled -> DUT ADC sample`.

Use the actual target servo controller and the intended PWM/ADC trigger scheme.

Decision thresholds:

- **available analog-settling margin > 10 us**:
  DAC80504/DAC80508-class low-cost architecture becomes viable;
- **margin 2–10 us**:
  keep AD3542R or evaluate 1-us DAC82001-class architecture;
- **margin < 2 us**:
  retain AD3542R fast-precision architecture.

This timing measurement is more valuable than selecting the DAC from headline
sample rate alone.

## 7. Pre-PCB proof path

Before spending money on the custom analog board, prove the end-to-end HIL loop
with an already available high-speed DAC module where possible:

1. capture the DUT six PWM edges on ZU2CG;
2. execute the PMSM/plant step;
3. update two fast analog current channels;
4. feed the outputs into a low-energy DUT ADC fixture;
5. measure actual PWM-to-analog and analog-to-ADC timing;
6. close the current loop at the real 20 kHz operating point;
7. then add the third current / Vbus channel as required.

A 14-bit 125 MSPS AD9767-class module is sufficient to validate the real-time
latency architecture even though it is not the final Rev.B DAC topology.

The result of this experiment determines whether the custom board needs
AD3542R-class performance or only a 5–10 us precision DAC.

## 8. Feasibility / success assessment

| Architecture | Technical feasibility | First-spin risk | Personal-project value |
|---|---|---|---|
| 8ch AD3542R-16 current Rev.B | high | medium | low-medium because cost is dominated by unused capability |
| 4ch AD3542R-12/16 selectable | **high** | **low-medium** | **high** |
| 4ch DAC80504 sensor-level | medium-high if timing margin >10 us | medium | very high if DUT is 0–5 V/unipolar |
| 4ch DAC81404 bipolar | medium-high if timing margin >10 us | medium-high | medium-high |
| 4ch DAC82001 1-us custom output stage | medium | high | medium |
| PWM / sigma-delta analog generation | high for slow auxiliary outputs | low | high for slow signals, poor for current-feedback fidelity |
| external AD9767/DAC5672 module | high for proof-of-concept | low-medium | **very high before custom PCB** |

The present Rev.B is therefore likely to work eventually, but the probability of
a cost-effective first prototype is materially improved by reducing the mandatory
high-speed analog population before Layout.

## 9. Final decision

**Recommended Rev.B personal-project baseline:**

- 4 fast AO, not 8 mandatory;
- retain expansion footprints for 8 AO;
- prefer AD3542R-12 as the first cost-down candidate, upgrade to -16 only if
  resolution testing requires it;
- make AD7606C optional for the first closed-loop prototype;
- perform end-to-end timing validation with an external high-speed DAC before
  final PCB Layout;
- only redesign around DAC80504/DAC81404 if measured DUT sample timing proves
  5–10 us DAC settling is acceptable.

This preserves the high-value part of Rev.B — FPGA plant, PWM capture, encoder
emulation, watchdog/interlock and real analog current-loop injection — while
cutting the first prototype component budget by roughly **44–56%** without
throwing away the full-capability path.

## 10. Layout hold criterion

Do not freeze the DAC/power/precision-analog placement until all three answers
are recorded:

1. required number of **fast** AO channels for the actual DUT;
2. minimum required effective DAC resolution at the actual sensor voltage range;
3. measured PWM-to-DUT-ADC timing margin.

Once those are known, the project can choose between:

- `AD3542R_FAST_4AO`;
- `LOW_COST_5US_4AO`;
- or the existing `AD3542R_FULL_8AO`.

PCB mechanical work unrelated to the DAC/power region may continue, but
precision-analog placement/routing should remain unfrozen until this decision is
closed.

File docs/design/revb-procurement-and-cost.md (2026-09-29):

# Rev.B Procurement and Cost Snapshot

**Snapshot date:** 2026-09-29  
**Design baseline:** `193d8bc61edc690c2f8518b8da784f56a821d872`  
**Planning FX:** 1 USD = 6.71 CNY. This is an engineering planning rate, not a
settlement/accounting rate.

## 1. Files

- Complete grouped BOM: `bom/revb-costed.csv`
- Machine-readable summary: `bom/revb-cost-summary.json`
- Price-source ledger: `bom/revb-pricing-sources.csv`
- Coverage checker: `python tools/check_revb_costed_bom.py`

The costed BOM is generated/reviewed against the **native schematic source**, not
against the older hand-maintained `revb-common.csv` list.

Coverage at this snapshot:

- 439 on-board physical instances;
- 431 populated instances;
- 8 DNP feedback capacitors;
- 139 grouped purchasing lines.

## 2. Component-cost result

| Build basis | Component estimate |
|---|---:|
| 1 fully stuffed Rev.B | **CNY 4,085.41** |
| 5 fully stuffed Rev.B boards | **CNY 17,153.21 total** |
| 5-board average component cost | **CNY 3,430.64 / board** |

The 5-board estimate applies known small-quantity breaks where they fit the actual
aggregate quantity. It does not pretend every distributor has identical stock or
price when the purchase order is placed.

**Excluded:** bare PCB, stencil, SMT/THT assembly, freight, VAT/import duties,
AXU2CGB host, J12/J15 mating connector pair while its exact MPN/stack height is
unbound, rework/scrap/yield reserve and qualification-fixture cost.

Because no production-ready `.kicad_pcb`/Gerber and fabricator stackup exist yet,
PCB/assembly cost is deliberately **TBD_VENDOR_QUOTE**, rather than embedding a
false-precision fabrication price in the BOM.

## 3. Main cost drivers

Using the qty-1 snapshot and planning FX:

| Item | Qty/board | Price basis | Approx CNY/board |
|---|---:|---:|---:|
| AD3542RBCPZ16 | 4 | USD 86.38 each | 2,318 |
| AD7606C-16BSTZ | 1 | USD 67.98 | 456 |
| ADG5412FBRUZ | 2 | USD 15.02 each | 202 |
| LT3045EMSE#PBF | 2 | USD 10.00 each | 134 |
| LT3094EMSE#PBF | 1 | USD 10.00 | 67 |
| ADR4525BRZ | 1 | USD 11.86 | 80 |
| LT8330ES6#TRMPBF | 1 | USD 8.27 | 55 |
| C5750X7R1V476M230KC | 1 | USD 5.55 | 37 |

The four DACs alone are about **56.7%** of the one-board component budget.
AD3542R + AD7606C-16 together are about **67.9%**. Prototype cost optimization
should therefore focus on purchasing quantity and staged population, not on
removing cents from ordinary passives.

## 4. Pricing evidence policy

`revb-costed.csv` intentionally distinguishes design truth from procurement
estimates.

### EXACT_QUOTE

Used when the schematic/mechanical contract binds the MPN and a current
authorized source was available. Examples include AD3542RBCPZ16,
AD7606C-16BSTZ, LT3045EMSE#PBF, TPS259474LRPWR, J5/J101/J501/J701 and C105.

### EXACT_MPN_NO_LIVE_QUOTE

Used when the exact manufacturer MPN is bound but the authorized source has no executable small-quantity quote at the snapshot. The BOM may carry a conservative engineering allowance, but the row must be re-quoted before PO. PESD15VL1BA,115 is the current example.

### CANDIDATE_QUOTE

Used for exact candidates already present in qualification evidence, for example
Coilcraft XAL50xx and selected TDK MLCCs. A quoted candidate is **not** a release
approval. Magnetic loss/saturation/thermal and MLCC derating evidence still
apply.

### BUDGET_GENERIC

Used for resistors, ordinary capacitors, test points and generic pin headers where
value/package are fixed but manufacturer MPN is not. These prices are conservative
small-quantity engineering allowances. The eventual release BOM must bind any
passive whose tolerance, voltage coefficient, ESR/ESL, pulse rating, temperature,
height or lifetime is electrically relevant.

### ORDERABLE_MPN_MISMATCH

U501 is the current case. The native schematic says `TPS3430DRCR`; TI's current
active orderable part page is `TPS3430WDRCR`. The BOM carries the latter only as a
budget/procurement candidate and **does not silently authorize substitution**.
Resolve the exact variant and update schematic + BOM together before fabrication.

## 5. Availability risks at this snapshot

- AD3542RBCPZ16 is the dominant cost item and has a long manufacturer lead-time
  indicator; secure prototype quantity early after the design is fabrication-ready.
- AD7606C-16BSTZ availability is tighter than common logic/passives.
- AP63201WU-7 and TPS70933DBVR showed no immediate DigiKey stock at the snapshot
  even though they remain active; recheck incoming dates or an approved source
  before PO.
- PESD15VL1BA,115 showed constrained authorized-distributor availability; do not
  silently swap TVS characteristics just because a similar SOD-323 part is stocked.
- J12/J15 exact host/mating connector MPN and stack height are not yet bound and
  are therefore intentionally excluded from the board component total.

## 6. Prototype procurement strategy

For the first physical spin, keep procurement separate from design release:

1. finish J12/J15 exact connector/stack binding and actual PCB Layout;
2. run PCB DRC and fabrication review;
3. re-quote all `EXACT_QUOTE` / `CANDIDATE_QUOTE` rows on the PO date;
4. resolve every `ORDERABLE_MPN_MISMATCH`;
5. freeze electrically significant generic passives to approved MPNs;
6. purchase enough long-lead precision ICs for rework/replacement, but avoid
   stuffing all prototype PCBs before first-board power/analog bring-up succeeds.

A practical engineering strategy remains to order multiple bare PCBs while
staging expensive AD3542R/AD7606 population. The exact number of fully populated
boards should be chosen after Layout and assembly quotes, not encoded as a release
requirement here.

## 7. Revalidation

Run:

```sh
python tools/check_revb_costed_bom.py
python -m unittest tests.test_revb_costed_bom -v
```

The checker ensures all native on-board references are covered exactly once,
DNP cost remains zero, 431/8 population counts remain intact and the U501 mismatch
cannot disappear merely by editing prose.

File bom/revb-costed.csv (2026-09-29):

line_id | refs | qty_per_board | populate | schematic_value | footprint | procurement_mpn | manufacturer | pricing_status | price_date | unit_price_currency | unit_price_qty1 | unit_price_5board_basis | planning_fx_cny_per_usd | extended_cny_one_board | extended_cny_five_boards | price_source | notes
001 | TP302 | 1 | YES | -5V2_PVSS | TestPoint:TestPoint_Pad_D1.0mm |  |  | BUDGET_GENERIC | 2026-09-29 | USD | 0.08000 | 0.06400 | 6.7100 | 0.54 | 2.15 |  | Engineering small-quantity budget; manufacturer MPN not source-bound
002 | TP301 | 1 | YES | -6V2_PRE | TestPoint:TestPoint_Pad_D1.0mm |  |  | BUDGET_GENERIC | 2026-09-29 | USD | 0.08000 | 0.06400 | 6.7100 | 0.54 | 2.15 |  | Engineering small-quantity budget; manufacturer MPN not source-bound
003 | TP211 | 1 | YES | +5V0_DAC | TestPoint:TestPoint_Pad_D1.0mm |  |  | BUDGET_GENERIC | 2026-09-29 | USD | 0.08000 | 0.06400 | 6.7100 | 0.54 | 2.15 |  | Engineering small-quantity budget; manufacturer MPN not source-bound
004 | TP212 | 1 | YES | +5V2_PVDD | TestPoint:TestPoint_Pad_D1.0mm |  |  | BUDGET_GENERIC | 2026-09-29 | USD | 0.08000 | 0.06400 | 6.7100 | 0.54 | 2.15 |  | Engineering small-quantity budget; manufacturer MPN not source-bound
005 | R652 R654 R850 R851 R852 R853 R854 R855 R856 R857 R858 R859 R860 R861 R862 R863 R864 R865 R901 R902 R906 R907 R911 R912 R916 R917 R1001 R1002 R1010 R1011 R1012 R1013 R1014 R1015 R1030 R1031 R1032 R1033 R1034 R1035 | 40 | YES | 100 | Resistor_SMD:R_0603_1608Metric |  |  | BUDGET_GENERIC | 2026-09-29 | USD | 0.01200 | 0.00960 | 6.7100 | 3.22 | 12.88 |  | Engineering small-quantity budget; manufacturer MPN not source-bound
006 | R1040 R1041 R1042 R1043 R1044 R1045 | 6 | YES | 100k | Resistor_SMD:R_0603_1608Metric |  |  | BUDGET_GENERIC | 2026-09-29 | USD | 0.01200 | 0.00960 | 6.7100 | 0.48 | 1.93 |  | Engineering small-quantity budget; manufacturer MPN not source-bound
007 | R201 | 1 | YES | 100k / EN default low | Resistor_SMD:R_0603_1608Metric |  |  | BUDGET_GENERIC | 2026-09-29 | USD | 0.01200 | 0.00960 | 6.7100 | 0.08 | 0.32 |  | Engineering small-quantity budget; manufacturer MPN not source-bound
008 | R554 | 1 | YES | 100k / Q401 B-E bleed | Resistor_SMD:R_0603_1608Metric |  |  | BUDGET_GENERIC | 2026-09-29 | USD | 0.01200 | 0.00960 | 6.7100 | 0.08 | 0.32 |  | Engineering small-quantity budget; manufacturer MPN not source-bound
009 | R556 | 1 | YES | 100k / Q402 B-E bleed | Resistor_SMD:R_0603_1608Metric |  |  | BUDGET_GENERIC | 2026-09-29 | USD | 0.01200 | 0.00960 | 6.7100 | 0.08 | 0.32 |  | Engineering small-quantity budget; manufacturer MPN not source-bound
010 | R550 | 1 | YES | 100k / unplugged ARM low | Resistor_SMD:R_0603_1608Metric |  |  | BUDGET_GENERIC | 2026-09-29 | USD | 0.01200 | 0.00960 | 6.7100 | 0.08 | 0.32 |  | Engineering small-quantity budget; manufacturer MPN not source-bound
011 | C601 C602 C603 C604 C605 C606 C607 C608 C609 C610 C651 C652 C653 C654 C801 C802 C803 C804 C806 C809 C901 C902 C903 C904 C911 C912 C913 C914 C1001 C1002 C1010 | 31 | YES | 100n | Capacitor_SMD:C_0603_1608Metric |  |  | BUDGET_GENERIC | 2026-09-29 | USD | 0.02500 | 0.02000 | 6.7100 | 5.20 | 20.80 |  | Engineering small-quantity budget; manufacturer MPN not source-bound
012 | C307 C327 C347 C367 | 4 | YES | 100nF | Capacitor_SMD:C_0603_1608Metric |  |  | BUDGET_GENERIC | 2026-09-29 | USD | 0.02500 | 0.02000 | 6.7100 | 0.67 | 2.68 |  | Engineering small-quantity budget; manufacturer MPN not source-bound
013 | C550 C551 C552 C553 C554 | 5 | YES | 100nF | Capacitor_SMD:C_0805_2012Metric |  |  | BUDGET_GENERIC | 2026-09-29 | USD | 0.04000 | 0.03200 | 6.7100 | 1.34 | 5.37 |  | Engineering small-quantity budget; manufacturer MPN not source-bound
014 | C109 C242 C262 C422 C431 C433 C501 C511 C521 C541 | 10 | YES | 100nF / 16V | Capacitor_SMD:C_0805_2012Metric |  |  | BUDGET_GENERIC | 2026-09-29 | USD | 0.04000 | 0.03200 | 6.7100 | 2.68 | 10.74 |  | Engineering small-quantity budget; manufacturer MPN not source-bound
015 | C210 C220 C230 | 3 | YES | 100nF / 16V bootstrap | Capacitor_SMD:C_0805_2012Metric |  |  | BUDGET_GENERIC | 2026-09-29 | USD | 0.04000 | 0.03200 | 6.7100 | 0.81 | 3.22 |  | Engineering small-quantity budget; manufacturer MPN not source-bound
016 | C106 C212 C222 C232 C412 | 5 | YES | 100nF / 50V | Capacitor_SMD:C_0805_2012Metric |  |  | BUDGET_GENERIC | 2026-09-29 | USD | 0.04000 | 0.03200 | 6.7100 | 1.34 | 5.37 |  | Engineering small-quantity budget; manufacturer MPN not source-bound
017 | C102 | 1 | YES | 100nF / 50V X7R | Capacitor_SMD:C_0805_2012Metric |  |  | BUDGET_GENERIC | 2026-09-29 | USD | 0.04000 | 0.03200 | 6.7100 | 0.27 | 1.07 |  | Engineering small-quantity budget; manufacturer MPN not source-bound
018 | R107 R244 R264 R424 R545 R602 R603 R604 R605 R607 R608 R651 R653 R703 R830 R831 R832 R833 R834 R903 R904 R905 R908 R909 R910 R913 R914 R915 R918 R919 R920 R1003 R1004 R1005 R1020 R1021 R1022 R1023 R1024 R1025 | 40 | YES | 10k | Resistor_SMD:R_0603_1608Metric |  |  | BUDGET_GENERIC | 2026-09-29 | USD | 0.01200 | 0.00960 | 6.7100 | 3.22 | 12.88 |  | Engineering small-quantity budget; manufacturer MPN not source-bound
019 | R551 | 1 | YES | 10k / default RESET asserted | Resistor_SMD:R_0603_1608Metric |  |  | BUDGET_GENERIC | 2026-09-29 | USD | 0.01200 | 0.00960 | 6.7100 | 0.08 | 0.32 |  | Engineering small-quantity budget; manufacturer MPN not source-bound
020 | R552 | 1 | YES | 10k / HOST ARM referenced pull-up | Resistor_SMD:R_0603_1608Metric |  |  | BUDGET_GENERIC | 2026-09-29 | USD | 0.01200 | 0.00960 | 6.7100 | 0.08 | 0.32 |  | Engineering small-quantity budget; manufacturer MPN not source-bound
021 | R530 | 1 | YES | 10k / open-drain pull-up | Resistor_SMD:R_0603_1608Metric |  |  | BUDGET_GENERIC | 2026-09-29 | USD | 0.01200 | 0.00960 | 6.7100 | 0.08 | 0.32 |  | Engineering small-quantity budget; manufacturer MPN not source-bound
022 | R105 R211 R221 R231 R243 R263 R423 R501 R511 R521 R540 R543 | 12 | YES | 10k 0.1% | Resistor_SMD:R_0603_1608Metric |  |  | BUDGET_GENERIC | 2026-09-29 | USD | 0.04000 | 0.03200 | 6.7100 | 3.22 | 12.88 |  | Engineering small-quantity budget; manufacturer MPN not source-bound
023 | C805 C810 | 2 | YES | 10u | Capacitor_SMD:C_0805_2012Metric |  |  | BUDGET_GENERIC | 2026-09-29 | USD | 0.04000 | 0.03200 | 6.7100 | 0.54 | 2.15 |  | Engineering small-quantity budget; manufacturer MPN not source-bound
024 | C241 C261 | 2 | YES | 10uF / 16V | Capacitor_SMD:C_0805_2012Metric |  |  | BUDGET_GENERIC | 2026-09-29 | USD | 0.22000 | 0.17600 | 6.7100 | 2.95 | 11.81 |  | Engineering small-quantity budget; manufacturer MPN not source-bound
025 | C414 C415 C421 | 3 | YES | 10uF / 16V X7R, 1210 | Capacitor_SMD:C_1210_3225Metric | C3225X7R1E106K250AC | TDK | CANDIDATE_QUOTE | 2026-09-29 | USD | 0.63000 | 0.39100 | 6.7100 | 12.68 | 39.35 | https://www.digikey.com/en/products/detail/tdk/C3225X7R1E106K250AC/1589879 | Candidate only; not release substitution approval
026 | C101 | 1 | YES | 10uF / 50V X7R | Capacitor_SMD:C_0805_2012Metric |  |  | BUDGET_GENERIC | 2026-09-29 | USD | 0.22000 | 0.17600 | 6.7100 | 1.48 | 5.90 |  | Engineering small-quantity budget; manufacturer MPN not source-bound
027 | C211 C221 C231 | 3 | YES | 10uF / 50V X7R | Capacitor_SMD:C_1210_3225Metric |  |  | BUDGET_GENERIC | 2026-09-29 | USD | 0.35000 | 0.28000 | 6.7100 | 7.05 | 28.18 |  | Engineering small-quantity budget; manufacturer MPN not source-bound
028 | C411 | 1 | YES | 10uF / 50V X7R, 1210 | Capacitor_SMD:C_1210_3225Metric |  |  | BUDGET_GENERIC | 2026-09-29 | USD | 0.35000 | 0.28000 | 6.7100 | 2.35 | 9.39 |  | Engineering small-quantity budget; manufacturer MPN not source-bound
029 | L201 | 1 | YES | 10uH / Isat >=3A / DCR <100mOhm | Inductor_SMD:L_Coilcraft_XAL5050-XXX | XAL5050-103MEC | Coilcraft | CANDIDATE_QUOTE | 2026-09-29 | USD | 3.02000 | 3.02000 | 6.7100 | 20.26 | 101.32 | https://www.coilcraft.com/zh-cn/products/power/shielded-inductors/molded-inductor/xal/xal50xx/xal5050-103/ | Existing qualification candidate; L(I,T), AC/core+winding loss and thermal remain open
030 | L301 L302 | 2 | YES | 10uH independent / Isat >=1.5A | Inductor_SMD:L_Coilcraft_XAL5050-XXX | XAL5050-103MEC | Coilcraft | CANDIDATE_QUOTE | 2026-09-29 | USD | 3.02000 | 3.02000 | 6.7100 | 40.53 | 202.64 | https://www.coilcraft.com/zh-cn/products/power/shielded-inductors/molded-inductor/xal/xal50xx/xal5050-103/ | Existing qualification candidate; L(I,T), AC/core+winding loss and thermal remain open
031 | R230 | 1 | YES | 12.4k 0.1% | Resistor_SMD:R_0603_1608Metric |  |  | BUDGET_GENERIC | 2026-09-29 | USD | 0.04000 | 0.03200 | 6.7100 | 0.27 | 1.07 |  | Engineering small-quantity budget; manufacturer MPN not source-bound
032 | R950 R951 R952 R953 R1006 | 5 | YES | 120 | Resistor_SMD:R_1206_3216Metric |  |  | BUDGET_GENERIC | 2026-09-29 | USD | 0.03500 | 0.02800 | 6.7100 | 1.17 | 4.70 |  | Engineering small-quantity budget; manufacturer MPN not source-bound
033 | R411 | 1 | YES | 147k 0.1% | Resistor_SMD:R_0603_1608Metric |  |  | BUDGET_GENERIC | 2026-09-29 | USD | 0.04000 | 0.03200 | 6.7100 | 0.27 | 1.07 |  | Engineering small-quantity budget; manufacturer MPN not source-bound
034 | R242 | 1 | YES | 150k 0.1% | Resistor_SMD:R_0603_1608Metric |  |  | BUDGET_GENERIC | 2026-09-29 | USD | 0.04000 | 0.03200 | 6.7100 | 0.27 | 1.07 |  | Engineering small-quantity budget; manufacturer MPN not source-bound
035 | R262 R422 | 2 | YES | 158k 0.1% | Resistor_SMD:R_0603_1608Metric |  |  | BUDGET_GENERIC | 2026-09-29 | USD | 0.04000 | 0.03200 | 6.7100 | 0.54 | 2.15 |  | Engineering small-quantity budget; manufacturer MPN not source-bound
036 | R421 | 1 | YES | 15k / 250mA nominal limit | Resistor_SMD:R_0603_1608Metric |  |  | BUDGET_GENERIC | 2026-09-29 | USD | 0.01200 | 0.00960 | 6.7100 | 0.08 | 0.32 |  | Engineering small-quantity budget; manufacturer MPN not source-bound
037 | R601 R606 | 2 | YES | 1k | Resistor_SMD:R_0603_1608Metric |  |  | BUDGET_GENERIC | 2026-09-29 | USD | 0.01200 | 0.00960 | 6.7100 | 0.16 | 0.64 |  | Engineering small-quantity budget; manufacturer MPN not source-bound
038 | R544 | 1 | YES | 1M / comparator hysteresis | Resistor_SMD:R_0603_1608Metric |  |  | BUDGET_GENERIC | 2026-09-29 | USD | 0.01200 | 0.00960 | 6.7100 | 0.08 | 0.32 |  | Engineering small-quantity budget; manufacturer MPN not source-bound
039 | R410 | 1 | YES | 1M 0.1% | Resistor_SMD:R_0603_1608Metric |  |  | BUDGET_GENERIC | 2026-09-29 | USD | 0.04000 | 0.03200 | 6.7100 | 0.27 | 1.07 |  | Engineering small-quantity budget; manufacturer MPN not source-bound
040 | C850 C851 C852 C853 C854 C855 C856 C857 | 8 | YES | 1n | Capacitor_SMD:C_0603_1608Metric |  |  | BUDGET_GENERIC | 2026-09-29 | USD | 0.05000 | 0.04000 | 6.7100 | 2.68 | 10.74 |  | Engineering small-quantity budget; manufacturer MPN not source-bound
041 | C540 | 1 | YES | 1nF / 16V | Capacitor_SMD:C_0805_2012Metric |  |  | BUDGET_GENERIC | 2026-09-29 | USD | 0.04000 | 0.03200 | 6.7100 | 0.27 | 1.07 |  | Engineering small-quantity budget; manufacturer MPN not source-bound
042 | C104 | 1 | YES | 1nF / 16V C0G | Capacitor_SMD:C_0805_2012Metric |  |  | BUDGET_GENERIC | 2026-09-29 | USD | 0.04000 | 0.03200 | 6.7100 | 0.27 | 1.07 |  | Engineering small-quantity budget; manufacturer MPN not source-bound
043 | C500 C510 C520 | 3 | YES | 1nF / 16V sense filter | Capacitor_SMD:C_0805_2012Metric |  |  | BUDGET_GENERIC | 2026-09-29 | USD | 0.04000 | 0.03200 | 6.7100 | 0.81 | 3.22 |  | Engineering small-quantity budget; manufacturer MPN not source-bound
044 | C807 C808 C921 C922 C1011 | 5 | YES | 1u | Capacitor_SMD:C_0805_2012Metric |  |  | BUDGET_GENERIC | 2026-09-29 | USD | 0.04000 | 0.03200 | 6.7100 | 1.34 | 5.37 |  | Engineering small-quantity budget; manufacturer MPN not source-bound
045 | C302 C304 C322 C324 C342 C344 C362 C364 | 8 | YES | 1uF | Capacitor_SMD:C_0805_2012Metric |  |  | BUDGET_GENERIC | 2026-09-29 | USD | 0.08000 | 0.06400 | 6.7100 | 4.29 | 17.18 |  | Engineering small-quantity budget; manufacturer MPN not source-bound
046 | C430 C432 | 2 | YES | 1uF / 16V | Capacitor_SMD:C_0805_2012Metric |  |  | BUDGET_GENERIC | 2026-09-29 | USD | 0.08000 | 0.06400 | 6.7100 | 1.07 | 4.29 |  | Engineering small-quantity budget; manufacturer MPN not source-bound
047 | C413 | 1 | YES | 1uF / 16V INTVCC ONLY | Capacitor_SMD:C_0805_2012Metric |  |  | BUDGET_GENERIC | 2026-09-29 | USD | 0.08000 | 0.06400 | 6.7100 | 0.54 | 2.15 |  | Engineering small-quantity budget; manufacturer MPN not source-bound
048 | C107 | 1 | YES | 1uF / 35V X7R | Capacitor_SMD:C_0805_2012Metric |  |  | BUDGET_GENERIC | 2026-09-29 | USD | 0.08000 | 0.06400 | 6.7100 | 0.54 | 2.15 |  | Engineering small-quantity budget; manufacturer MPN not source-bound
049 | C410 | 1 | YES | 1uF / 50V X7R energy transfer | Capacitor_SMD:C_1210_3225Metric | CGA6L2X7R1H105K160AA | TDK | CANDIDATE_QUOTE | 2026-09-29 | USD | 0.35000 | 0.20700 | 6.7100 | 2.35 | 6.94 | https://www.digikey.com/en/products/detail/tdk/CGA6L2X7R1H105K160AA/2443191 | Existing C410 candidate; qualification/lifecycle caveat retained
050 | TP203 | 1 | YES | 1V8_D | TestPoint:TestPoint_Pad_D1.0mm |  |  | BUDGET_GENERIC | 2026-09-29 | USD | 0.08000 | 0.06400 | 6.7100 | 0.54 | 2.15 |  | Engineering small-quantity budget; manufacturer MPN not source-bound
051 | R106 | 1 | YES | 2.21k 1% / 1.51A nominal | Resistor_SMD:R_0603_1608Metric |  |  | BUDGET_GENERIC | 2026-09-29 | USD | 0.01200 | 0.00960 | 6.7100 | 0.08 | 0.32 |  | Engineering small-quantity budget; manufacturer MPN not source-bound
052 | R212 R222 R232 R412 | 4 | YES | 2.2k bleeder | Resistor_SMD:R_0603_1608Metric |  |  | BUDGET_GENERIC | 2026-09-29 | USD | 0.01200 | 0.00960 | 6.7100 | 0.32 | 1.29 |  | Engineering small-quantity budget; manufacturer MPN not source-bound
053 | R701 | 1 | YES | 220 1% | Resistor_SMD:R_0603_1608Metric |  |  | BUDGET_GENERIC | 2026-09-29 | USD | 0.01200 | 0.00960 | 6.7100 | 0.08 | 0.32 |  | Engineering small-quantity budget; manufacturer MPN not source-bound
054 | C213 C214 C223 C224 C233 C234 C243 C244 C263 C264 C423 C424 | 12 | YES | 22uF / 16V X7R, 1210 | Capacitor_SMD:C_1210_3225Metric | C3225X7R1C226M250AC | TDK | CANDIDATE_QUOTE | 2026-09-29 | USD | 0.62000 | 0.38000 | 6.7100 | 49.92 | 152.99 | https://www.digikey.com/en/products/detail/tdk/C3225X7R1C226M250AC/1587497 | Existing candidate; DC-bias/temperature/aging/RMS qualification open
055 | F101 | 1 | YES | 2A backup fuse / 0451002.MRL | Fuse:Fuse_Littelfuse-NANO2-451_453 | 0451002.MRL | Littelfuse | EXACT_QUOTE | 2026-09-29 | USD | 2.47000 | 1.89300 | 6.7100 | 16.57 | 63.51 | https://www.digikey.com/en/products/detail/littelfuse-inc/0451002-MRL/700822 | DigiKey qty1 / qty10
056 | C103 | 1 | YES | 3.3nF / 50V C0G | Capacitor_SMD:C_0805_2012Metric |  |  | BUDGET_GENERIC | 2026-09-29 | USD | 0.04000 | 0.03200 | 6.7100 | 0.27 | 1.07 |  | Engineering small-quantity budget; manufacturer MPN not source-bound
057 | R541 R542 | 2 | YES | 30k 0.1% | Resistor_SMD:R_0603_1608Metric |  |  | BUDGET_GENERIC | 2026-09-29 | USD | 0.04000 | 0.03200 | 6.7100 | 0.54 | 2.15 |  | Engineering small-quantity budget; manufacturer MPN not source-bound
058 | R220 | 1 | YES | 31.2k 0.1% | Resistor_SMD:R_0603_1608Metric |  |  | BUDGET_GENERIC | 2026-09-29 | USD | 0.04000 | 0.03200 | 6.7100 | 0.27 | 1.07 |  | Engineering small-quantity budget; manufacturer MPN not source-bound
059 | R500 | 1 | YES | 32.8k 0.1% | Resistor_SMD:R_0603_1608Metric |  |  | BUDGET_GENERIC | 2026-09-29 | USD | 0.04000 | 0.03200 | 6.7100 | 0.27 | 1.07 |  | Engineering small-quantity budget; manufacturer MPN not source-bound
060 | R801 R802 R803 R804 R805 R820 R821 R822 R823 R824 R825 R826 R827 R828 | 14 | YES | 33 | Resistor_SMD:R_0603_1608Metric |  |  | BUDGET_GENERIC | 2026-09-29 | USD | 0.01200 | 0.00960 | 6.7100 | 1.13 | 4.51 |  | Engineering small-quantity budget; manufacturer MPN not source-bound
061 | TP202 | 1 | YES | 3V3_D | TestPoint:TestPoint_Pad_D1.0mm |  |  | BUDGET_GENERIC | 2026-09-29 | USD | 0.08000 | 0.06400 | 6.7100 | 0.54 | 2.15 |  | Engineering small-quantity budget; manufacturer MPN not source-bound
062 | R1050 R1051 | 2 | YES | 4.7k | Resistor_SMD:R_0603_1608Metric |  |  | BUDGET_GENERIC | 2026-09-29 | USD | 0.01200 | 0.00960 | 6.7100 | 0.16 | 0.64 |  | Engineering small-quantity budget; manufacturer MPN not source-bound
063 | C416 | 1 | YES | 4.7pF / 50V C0G feedforward | Capacitor_SMD:C_0805_2012Metric |  |  | BUDGET_GENERIC | 2026-09-29 | USD | 0.04000 | 0.03200 | 6.7100 | 0.27 | 1.07 |  | Engineering small-quantity budget; manufacturer MPN not source-bound
064 | C303 C305 C306 C323 C325 C326 C343 C345 C346 C363 C365 C366 | 12 | YES | 4.7uF | Capacitor_SMD:C_0805_2012Metric |  |  | BUDGET_GENERIC | 2026-09-29 | USD | 0.12000 | 0.09600 | 6.7100 | 9.66 | 38.65 |  | Engineering small-quantity budget; manufacturer MPN not source-bound
065 | C108 | 1 | YES | 4.7uF / 16V effective >=2.2uF | Capacitor_SMD:C_0805_2012Metric |  |  | BUDGET_GENERIC | 2026-09-29 | USD | 0.12000 | 0.09600 | 6.7100 | 0.81 | 3.22 |  | Engineering small-quantity budget; manufacturer MPN not source-bound
066 | L203 | 1 | YES | 4.7uH / Isat >=3A / DCR <100mOhm | Inductor_SMD:L_Coilcraft_XAL5030 | XAL5030-472MEC | Coilcraft | CANDIDATE_QUOTE | 2026-09-29 | USD | 2.74000 | 2.74000 | 6.7100 | 18.39 | 91.93 | https://www.coilcraft.com/en-us/products/power/shielded-inductors/molded-inductor/xal/xal50xx/xal5030-472/ | Coilcraft direct qty1 sample price; candidate only
067 | C240 C260 C420 | 3 | YES | 470nF / 16V SET | Capacitor_SMD:C_0805_2012Metric |  |  | BUDGET_GENERIC | 2026-09-29 | USD | 0.04000 | 0.03200 | 6.7100 | 0.81 | 3.22 |  | Engineering small-quantity budget; manufacturer MPN not source-bound
068 | R553 | 1 | YES | 47k / default fault bias | Resistor_SMD:R_0603_1608Metric |  |  | BUDGET_GENERIC | 2026-09-29 | USD | 0.01200 | 0.00960 | 6.7100 | 0.08 | 0.32 |  | Engineering small-quantity budget; manufacturer MPN not source-bound
069 | R555 | 1 | YES | 47k / release base limit | Resistor_SMD:R_0603_1608Metric |  |  | BUDGET_GENERIC | 2026-09-29 | USD | 0.01200 | 0.00960 | 6.7100 | 0.08 | 0.32 |  | Engineering small-quantity budget; manufacturer MPN not source-bound
070 | C105 | 1 | YES | 47uF / 35V X7R / TDK C5750X7R1V476M230KC | Capacitor_SMD:TDK_C5750X7R1V476M230KC | C5750X7R1V476M230KC | TDK | EXACT_QUOTE | 2026-09-29 | USD | 5.55000 | 4.01700 | 6.7100 | 37.24 | 134.77 | https://www.digikey.com/en/products/detail/tdk/C5750X7R1V476M230KC/15930210 | DigiKey qty1 / qty10
071 | R240 R520 | 2 | YES | 49.9k 0.1% | Resistor_SMD:R_0603_1608Metric |  |  | BUDGET_GENERIC | 2026-09-29 | USD | 0.04000 | 0.03200 | 6.7100 | 0.54 | 2.15 |  | Engineering small-quantity budget; manufacturer MPN not source-bound
072 | R241 R261 | 2 | YES | 499R / 300mA nominal limit | Resistor_SMD:R_0603_1608Metric |  |  | BUDGET_GENERIC | 2026-09-29 | USD | 0.01200 | 0.00960 | 6.7100 | 0.16 | 0.64 |  | Engineering small-quantity budget; manufacturer MPN not source-bound
073 | R260 R420 | 2 | YES | 52.0k 0.1% | Resistor_SMD:R_0603_1608Metric |  |  | BUDGET_GENERIC | 2026-09-29 | USD | 0.04000 | 0.03200 | 6.7100 | 0.54 | 2.15 |  | Engineering small-quantity budget; manufacturer MPN not source-bound
074 | R300 R301 R320 R321 R340 R341 R360 R361 | 8 | YES | 52.3R START | Resistor_SMD:R_0603_1608Metric |  |  | BUDGET_GENERIC | 2026-09-29 | USD | 0.01200 | 0.00960 | 6.7100 | 0.64 | 2.58 |  | Engineering small-quantity budget; manufacturer MPN not source-bound
075 | R104 | 1 | YES | 56.2k 0.1% | Resistor_SMD:R_0603_1608Metric |  |  | BUDGET_GENERIC | 2026-09-29 | USD | 0.04000 | 0.03200 | 6.7100 | 0.27 | 1.07 |  | Engineering small-quantity budget; manufacturer MPN not source-bound
076 | L202 | 1 | YES | 6.8uH / Isat >=3A / DCR <100mOhm | Inductor_SMD:L_Coilcraft_XAL5050-XXX | XAL5050-682MEC | Coilcraft | CANDIDATE_QUOTE | 2026-09-29 | USD | 3.02000 | 3.02000 | 6.7100 | 20.26 | 101.32 | https://www.coilcraft.com/zh-cn/products/power/shielded-inductors/molded-inductor/xal/xal50xx/xal5050-682/ | Existing qualification candidate; not release-qualified
077 | R102 R103 | 2 | YES | 60.4k 0.1% | Resistor_SMD:R_0603_1608Metric |  |  | BUDGET_GENERIC | 2026-09-29 | USD | 0.04000 | 0.03200 | 6.7100 | 0.54 | 2.15 |  | Engineering small-quantity budget; manufacturer MPN not source-bound
078 | R210 R510 | 2 | YES | 67.3k 0.1% | Resistor_SMD:R_0603_1608Metric |  |  | BUDGET_GENERIC | 2026-09-29 | USD | 0.04000 | 0.03200 | 6.7100 | 0.54 | 2.15 |  | Engineering small-quantity budget; manufacturer MPN not source-bound
079 | R702 | 1 | YES | 680 1% | Resistor_SMD:R_0603_1608Metric |  |  | BUDGET_GENERIC | 2026-09-29 | USD | 0.01200 | 0.00960 | 6.7100 | 0.08 | 0.32 |  | Engineering small-quantity budget; manufacturer MPN not source-bound
080 | R101 | 1 | YES | 680k 0.1% | Resistor_SMD:R_0603_1608Metric |  |  | BUDGET_GENERIC | 2026-09-29 | USD | 0.04000 | 0.03200 | 6.7100 | 0.27 | 1.07 |  | Engineering small-quantity budget; manufacturer MPN not source-bound
081 | TP201 | 1 | YES | 6V2_PRE | TestPoint:TestPoint_Pad_D1.0mm |  |  | BUDGET_GENERIC | 2026-09-29 | USD | 0.08000 | 0.06400 | 6.7100 | 0.54 | 2.15 |  | Engineering small-quantity budget; manufacturer MPN not source-bound
082 | U20 U21 U22 U23 | 4 | YES | AD3542RBCPZ16 | Package_DFN_QFN:AnalogDevices_CP-28-15_AD3542R | AD3542RBCPZ16 | Analog Devices | EXACT_QUOTE | 2026-09-29 | USD | 86.38000 | 70.55071 | 6.7100 | 2318.44 | 9467.91 | https://www.digikey.com/en/products/detail/analog-devices-inc/AD3542RBCPZ16/16580691 | DigiKey qty1 / qty14
083 | U801 | 1 | YES | AD7606C-16BSTZ | Package_QFP:LQFP-64_10x10mm_P0.5mm | AD7606C-16BSTZ | Analog Devices | EXACT_QUOTE | 2026-09-29 | USD | 67.98000 | 67.98000 | 6.7100 | 456.15 | 2280.73 | https://www.digikey.com/en/products/detail/analog-devices-inc/AD7606C-16BSTZ/13918940 | DigiKey qty1; qty18 break not applied to 5-board build
084 | TP801 | 1 | YES | ADC_FRSTDATA | TestPoint:TestPoint_Pad_D1.0mm |  |  | BUDGET_GENERIC | 2026-09-29 | USD | 0.08000 | 0.06400 | 6.7100 | 0.54 | 2.15 |  | Engineering small-quantity budget; manufacturer MPN not source-bound
085 | U601 U602 | 2 | YES | ADG5412FBRUZ | Package_SO:TSSOP-16_4.4x5mm_P0.65mm | ADG5412FBRUZ | Analog Devices | EXACT_QUOTE | 2026-09-29 | USD | 15.02000 | 11.86800 | 6.7100 | 201.57 | 796.34 | https://www.digikey.com/en/products/detail/analog-devices-inc/ADG5412FBRUZ/5011605 | DigiKey qty1 / qty10
086 | U303 | 1 | YES | ADR4525BRZ / 2.5V reference | Package_SO:SOIC-8_3.9x4.9mm_P1.27mm | ADR4525BRZ | Analog Devices | EXACT_QUOTE | 2026-09-29 | USD | 11.86000 | 11.86000 | 6.7100 | 79.58 | 397.90 | https://www.digikey.com/en/products/detail/analog-devices-inc/ADR4525BRZ/3196871 | DigiKey qty1
087 | J801 | 1 | YES | AI0..7 / GND - LOW ENERGY +/-10V | Connector_PinHeader_2.54mm:PinHeader_2x08_P2.54mm_Vertical |  |  | BUDGET_GENERIC | 2026-09-29 | USD | 0.60000 | 0.48000 | 6.7100 | 4.03 | 16.10 |  | Engineering small-quantity budget; manufacturer MPN not source-bound
088 | U201 U202 U203 | 3 | YES | AP63201WU-7 / 500kHz FPWM | Package_TO_SOT_SMD:TSOT-23-6 | AP63201WU-7 | Diodes Inc. | EXACT_QUOTE | 2026-09-29 | USD | 0.93000 | 0.66200 | 6.7100 | 18.72 | 66.63 | https://www.digikey.com/en/products/detail/diodes-incorporated/AP63201WU-7/9858425 | DigiKey qty1 / qty10; stock lead-time must be rechecked
089 | U701 | 1 | YES | AQY212GS | Package_SO:SO-4_4.4x4.3mm_P2.54mm | AQY212GS | Panasonic | EXACT_QUOTE | 2026-09-29 | USD | 3.18000 | 3.18000 | 6.7100 | 21.34 | 106.69 | https://www.digikey.com/en/products/detail/panasonic-industry/AQY212GS/571632 | DigiKey qty1
090 | J1002 | 1 | YES | AUX 3.3V LOGIC / GND | Connector_PinHeader_2.54mm:PinHeader_2x04_P2.54mm_Vertical |  |  | BUDGET_GENERIC | 2026-09-29 | USD | 0.35000 | 0.28000 | 6.7100 | 2.35 | 9.39 |  | Engineering small-quantity budget; manufacturer MPN not source-bound
091 | D401 | 1 | YES | BAT54H / input negative clamp | Diode_SMD:D_SOD-123 |  |  | BUDGET_GENERIC | 2026-09-29 | USD | 0.10000 | 0.08000 | 6.7100 | 0.67 | 2.68 |  | Engineering small-quantity budget; manufacturer MPN not source-bound
092 | D402 | 1 | YES | BAT54H / input upper clamp | Diode_SMD:D_SOD-123 |  |  | BUDGET_GENERIC | 2026-09-29 | USD | 0.10000 | 0.08000 | 6.7100 | 0.67 | 2.68 |  | Engineering small-quantity budget; manufacturer MPN not source-bound
093 | D403 | 1 | YES | BAT54H / reference upper clamp | Diode_SMD:D_SOD-123 |  |  | BUDGET_GENERIC | 2026-09-29 | USD | 0.10000 | 0.08000 | 6.7100 | 0.67 | 2.68 |  | Engineering small-quantity budget; manufacturer MPN not source-bound
094 | C300 C320 C340 C360 | 4 | DNP | DNP C0G CFB0 REVIEW | Capacitor_SMD:C_0603_1608Metric |  |  | DNP | 2026-09-29 | USD | 0.00000 | 0.00000 | 6.7100 | 0.00 | 0.00 |  | Not fitted; procurement cost excluded
095 | C301 C321 C341 C361 | 4 | DNP | DNP C0G CFB1 REVIEW | Capacitor_SMD:C_0603_1608Metric |  |  | DNP | 2026-09-29 | USD | 0.00000 | 0.00000 | 6.7100 | 0.00 | 0.00 |  | Not fitted; procurement cost excluded
096 | TP651 | 1 | YES | FF0_N | TestPoint:TestPoint_Pad_D1.0mm |  |  | BUDGET_GENERIC | 2026-09-29 | USD | 0.08000 | 0.06400 | 6.7100 | 0.54 | 2.15 |  | Engineering small-quantity budget; manufacturer MPN not source-bound
097 | TP652 | 1 | YES | FF1_N | TestPoint:TestPoint_Pad_D1.0mm |  |  | BUDGET_GENERIC | 2026-09-29 | USD | 0.08000 | 0.06400 | 6.7100 | 0.54 | 2.15 |  | Engineering small-quantity budget; manufacturer MPN not source-bound
098 | TP402 | 1 | YES | HIL_FAULT_N | TestPoint:TestPoint_Pad_D1.0mm |  |  | BUDGET_GENERIC | 2026-09-29 | USD | 0.08000 | 0.06400 | 6.7100 | 0.54 | 2.15 |  | Engineering small-quantity budget; manufacturer MPN not source-bound
099 | TP401 | 1 | YES | HIL_WDI | TestPoint:TestPoint_Pad_D1.0mm |  |  | BUDGET_GENERIC | 2026-09-29 | USD | 0.08000 | 0.06400 | 6.7100 | 0.54 | 2.15 |  | Engineering small-quantity budget; manufacturer MPN not source-bound
100 | J1003 | 1 | YES | I2C 3.3V / GND | Connector_PinHeader_2.54mm:PinHeader_1x04_P2.54mm_Vertical |  |  | BUDGET_GENERIC | 2026-09-29 | USD | 0.20000 | 0.16000 | 6.7100 | 1.34 | 5.37 |  | Engineering small-quantity budget; manufacturer MPN not source-bound
101 | U211 U212 | 2 | YES | LT3045EMSE#PBF / complete 12+EP pins | Package_SO:MSOP-12-1EP_3x4mm_P0.65mm_EP1.65x2.85mm | LT3045EMSE#PBF | Analog Devices | EXACT_QUOTE | 2026-09-29 | USD | 10.00000 | 7.79600 | 6.7100 | 134.20 | 523.11 | https://www.digikey.com/en/products/detail/analog-devices-inc/LT3045EMSE-PBF/6234771 | DigiKey qty1 / qty10
102 | U302 | 1 | YES | LT3094EMSE#PBF / EP13=negative IN | Package_SO:MSOP-12-1EP_3x4mm_P0.65mm_EP1.65x2.85mm | LT3094EMSE#PBF | Analog Devices | EXACT_QUOTE | 2026-09-29 | USD | 10.00000 | 10.00000 | 6.7100 | 67.10 | 335.50 | https://www.digikey.com/en/products/detail/linear-technology-analog-devices/LT3094EMSE-PBF/LT3094EMSE-PBF-ND/9607268 | DigiKey qty1
103 | U301 | 1 | YES | LT8330ES6#TRMPBF / 2MHz | Package_TO_SOT_SMD:TSOT-23-6 | LT8330ES6#TRMPBF | Analog Devices | EXACT_QUOTE | 2026-09-29 | USD | 8.27000 | 8.27000 | 6.7100 | 55.49 | 277.46 | https://www.digikey.com/en/products/detail/analog-devices-inc/LT8330ES6-TRMPBF/5361665 | DigiKey qty1
104 | Q701 | 1 | YES | MMBT3904 | Package_TO_SOT_SMD:SOT-23 |  |  | BUDGET_GENERIC | 2026-09-29 | USD | 0.07000 | 0.05600 | 6.7100 | 0.47 | 1.88 |  | Engineering small-quantity budget; manufacturer MPN not source-bound
105 | Q401 | 1 | YES | MMBT3904,215 / default fault sink | Package_TO_SOT_SMD:SOT-23 |  |  | BUDGET_GENERIC | 2026-09-29 | USD | 0.07000 | 0.05600 | 6.7100 | 0.47 | 1.88 |  | Engineering small-quantity budget; manufacturer MPN not source-bound
106 | Q402 | 1 | YES | MMBT3904,215 / qualified release | Package_TO_SOT_SMD:SOT-23 |  |  | BUDGET_GENERIC | 2026-09-29 | USD | 0.07000 | 0.05600 | 6.7100 | 0.47 | 1.88 |  | Engineering small-quantity budget; manufacturer MPN not source-bound
107 | J701 | 1 | YES | Molex Micro-Fit 3.0 43045-0212 / DUT PERMIT FLOATING NO | Connector_Molex:Molex_Micro-Fit_3.0_43045-0212_2x01_P3.00mm_Vertical | 0430450212 | Molex | EXACT_QUOTE | 2026-09-29 | USD | 0.91000 | 0.76900 | 6.7100 | 6.11 | 25.80 | https://www.digikey.com/en/products/detail/molex/0430450212/252502 | DigiKey qty1 / qty10
108 | D1201 D1202 D1203 D1204 D1205 D1206 D1207 D1208 D1211 D1212 D1213 D1214 D1215 D1216 D1217 D1218 | 16 | YES | PESD15VL1BA | Diode_SMD:D_SOD-323 | PESD15VL1BA,115 | Nexperia | EXACT_MPN_NO_LIVE_QUOTE | 2026-09-29 | USD | 0.45000 | 0.45000 | 6.7100 | 48.31 | 241.56 | https://www.digikey.com/en/products/detail/nexperia-usa-inc/PESD15VL1BA-115/1157420 | Current authorized-distributor stock constrained; $0.45 conservative budget pending live quote
109 | D1221 D1222 D1223 D1224 D1225 D1226 D1231 D1232 D1233 D1234 D1235 D1236 D1241 D1242 D1261 D1262 | 16 | YES | PESD5V0S1BA | Diode_SMD:D_SOD-323 | PESD5V0S1BA,115 | Nexperia | EXACT_QUOTE | 2026-09-29 | USD | 0.41000 | 0.24900 | 6.7100 | 44.02 | 133.66 | https://www.digikey.com/en/products/detail/nexperia-usa-inc/PESD5V0S1BA-115/1530843 | Packaging suffix selected for budgeting; base device matches schematic
110 | J5 | 1 | YES | Phoenix MC 1,5/10-G-3,5 / 1844294 / AO0..AO7+2GND | Connector_Phoenix_MC:PhoenixContact_MC_1,5_10-G-3.5_1x10_P3.50mm_Horizontal | 1844294 | Phoenix Contact | EXACT_QUOTE | 2026-09-29 | USD | 4.15000 | 3.37200 | 6.7100 | 27.85 | 113.13 | https://www.digikey.com/en/products/detail/phoenix-contact/1844294/349201 | DigiKey qty1 / qty10
111 | J501 | 1 | YES | Phoenix MC 1,5/2-G-3,5 / 1844210 / 3.3V DRY CONTACT ONLY | Connector_Phoenix_MC:PhoenixContact_MC_1,5_2-G-3.5_1x02_P3.50mm_Horizontal | 1844210 | Phoenix Contact | EXACT_QUOTE | 2026-09-29 | USD | 0.83000 | 0.67600 | 6.7100 | 5.57 | 22.68 | https://www.digikey.com/en/products/detail/phoenix-contact/1844210/349195 | DigiKey qty1 / qty10
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

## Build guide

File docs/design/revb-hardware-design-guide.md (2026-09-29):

# Rev.B Hardware Design Guide

> **Revision:** Rev.B  
> **Design snapshot:** 2026-09-29 / source baseline `193d8bc61edc690c2f8518b8da784f56a821d872`  
> **Purpose:** single engineering entry point for schematic intent, power calculations, I/O definition, PCB constraints, procurement and first-board bring-up.  
> **Release boundary:** `layout_allowed=true`, `fabrication_allowed=false`, `release_allowed=false`.

This document consolidates the Rev.B design rationale. It does **not** replace the
native KiCad source or machine-readable contracts. If prose conflicts with an
active contract, use the native schematic plus the contract as the source of truth
and fix this guide in the same change.

## 1. Source-of-truth hierarchy

1. Native schematic:
   `hardware/kicad/revB/axu2cgb_expansion/servohil_io_revB.kicad_pro`
2. Carrier physical pin facts:
   `hardware/carriers/axu2cgb/physical_pinout.csv`
3. Rev.B signal assignment:
   `hardware/carriers/axu2cgb/assignments.csv`
4. Electrical I/O contract:
   `hardware/revB/io_contract.json`
5. Layout / release contracts:
   `hardware/revB/gates.json`,
   `hardware/revB/layout_entry_contract.json`,
   `hardware/revB/pcb_layout_contract.json`,
   `hardware/revB/pcb_design_rules.json`
6. Component/evidence contracts:
   `hardware/revB/component_evidence_sources.json`,
   `hardware/revB/qualification_requirements.json`,
   `hardware/revB/verification_plans/`
7. Complete grouped costed BOM:
   `bom/revb-costed.csv` and `bom/revb-cost-summary.json`

Historical review checkpoints under `docs/review/` are evidence of the state at
their recorded commit/date. They must not override current machine-readable gates.

## 2. Architecture

Rev.B is a **single-ZU2CG HIL expansion board** for the original ALINX AXU2CGB.
The ZU2CG performs Plant and real-time I/O. There is no second FPGA on this board.

Functional paths:

- **8 AO:** 4 × AD3542RBCPZ16 (2 channels each) -> source/isolation network ->
  2 × ADG5412F protected analog switches -> J5.
- **8 AI:** J801 -> connector protection -> per-channel RC frontend ->
  AD7606C-16BSTZ -> eight serial DOUT lanes to ZU2CG.
- **PWM:** six 3.3 V laboratory PWM inputs -> protection/buffer -> ZU2CG.
- **Encoders:** two SSI/BiSS ports, each with clock and data differential pairs
  using THVD1450.
- **RS-485 / AUX / management:** one gated RS-485 path, 3.3 V AUX logic and I2C.
- **Independent hardware supervision:** input qualification, rail monitoring,
  explicit arm/re-arm state, window watchdog, physical AO disconnect and floating
  DUT-permit contact.

The board accepts **regulated 9–15 V SELV**. It is not a 48/67 V motor-bus input.

## 3. Schematic page map and design intent

The root plus 14 child sheets form the current 15-page design.

| Sheet | Purpose | Layout-critical intent |
|---|---|---|
| root | hierarchy and cross-sheet power/control | do not create new global nets for page-local wiring |
| 01_carrier_interface | AXU2CGB J12/J15 logical boundary | preserve 1.8 V J12 vs 3.3 V J15 domains |
| 03_peripheral_boundaries | PWM/AUX/I2C/RS-485 | connector protection before victim; 3.3 V lab logic only |
| 04_dac_0_3 | U20/U21, AO0..3 | keep DAC/reference/feedback compact |
| 05_dac_4_7 | U22/U23, AO4..7 | same geometry and return strategy as first DAC bank |
| 06_analog_outputs | AO connector and protection | short analog paths; J5 pins 9/10 are signal GND |
| 10_input_protection | fuse/reverse diode/TVS/eFuse/AON | physical current flow J101 -> F101 -> D101/D102 -> U101 -> C105 |
| 20_positive_rails | three bucks + LT3045 rails | minimize switch nodes; separate switchers from precision analog |
| 30_negative_reference | LT8330, LT3094, ADR4525 | compact Cuk loop; isolate negative switch node from ADC/DAC |
| 40_power_supervision | rail-valid detection / arm latch | power-qualified defaults must fail closed |
| 41_power_status | diagnostic status output | avoid powered-off backfeed into host |
| 50_watchdog_interlock | independent watchdog/interlock | watchdog must not depend on software continuing to execute |
| 60_dut_permit | floating PhotoMOS permit | floating contact; do not clamp to board GND |
| 70_adc_frontend | AD7606C-16 + 8 AI RC channels | protect at connector; compact REF/REGCAP and input RC |
| 80_encoder_phy | dual SSI/BiSS transceivers | coupled pairs, short stubs, optional 120-ohm termination |

## 4. Power tree and calculations

### 4.1 Input protection

Nominal input range: **9–15 V regulated SELV**.

`J101 -> F101 -> D101 -> D102 -> TPS259474L -> VIN_PROT`

- F101: 2 A Littelfuse 0451002.MRL backup fuse.
- D101: SS34 series reverse-polarity diode.
- D102: 16 V standoff TVS candidate.
- U101: TPS259474L latched circuit breaker/eFuse.
- RILM = 2.21 kOhm gives nominal trip:
  `I_trip ~= 3334 / 2210 ~= 1.51 A`.
- UV/OV divider 680 k / 60.4 k / 60.4 k gives approximately
  **7.95 V UV** and **15.91 V OV** at the eFuse input.
- PG threshold is approximately **7.94 V**.
- U102 TPS70933 supplies the always-on 3.3 V domain. Its EN is intentionally
  left open per the device's internal pull-up behavior; do not tie EN to the raw
  12 V input.

These are design calculations, not surge, startup, current-limit or thermal
qualification.

### 4.2 Positive switchers

Three AP63201WU-7 forced-PWM stages use
`Vout = 0.8 * (1 + Rupper/Rlower)`.

| Rail | Rupper/Rlower | Calculated nominal | L nominal |
|---|---:|---:|---:|
| 6V2_PRE | 67.3k / 10k | 6.184 V | 10 uH |
| 3V3_D | 31.2k / 10k | 3.296 V | 6.8 uH |
| 1V8_D | 12.4k / 10k | 1.792 V | 4.7 uH |

The original worst-case screen at VIN=15 V, f=450 kHz and L=80% nominal gave
approximate inductor ripple of **1.01 A / 1.05 A / 0.93 A** respectively.
Current system-level screening budgets have subsequently increased to
6V2_PRE=0.55 A, 3V3_D=0.70 A and 1V8_D=0.32 A; therefore the original peak-current
numbers must not be reused as a final release proof.

Each switching island should have a very small SW copper region and local return.
Do not route SW copper under ADC, DAC, VREF or low-noise LDO circuitry.

### 4.3 Positive low-noise rails

Two LT3045 stages produce the precision positive analog rails.

- 49.9 k SET -> about **4.990 V**.
- 52.0 k SET -> about **5.200 V**.
- 499 Ohm ILIM -> about **300 mA** nominal current limit.
- OUTS is Kelvin-connected to the output capacitor.
- Existing analytical dissipation checkpoints are about **0.239 W** and
  **0.118 W** for the reviewed loads; mounted-board temperature remains open.

### 4.4 Negative rail

U301 LT8330 uses the reviewed two-inductor inverting/Cuk path:

`VIN -> L301 -> SW_NEG -> C410 -> NEG_X -> L302 -> negative output`.

A 1 M / 147 k FBX network gives approximately **-6.242 V**. U302 LT3094 then
creates the low-noise **-5.2 V PVSS** rail; its exposed pad is negative IN,
**not GND**. The transfer capacitor C410 must tolerate VIN + |Vout| and ripple.

### 4.5 Reference and DAC rail-margin caveat

ADR4525 generates **VREF_2V5** for the four AD3542R devices. Do not assume
multiple internal DAC references may be paralleled.

The EDV checkpoint intentionally retains a supply/headroom conflict rather than
hiding it:

- calculated DAC rail span: about **10.622608 V** against the 10.6 V screen;
- minimum +/-5 V output headroom in the reviewed corner: about **0.088904 V**
  against a 0.2 V recommended target;
- one reviewed RSET feasibility screen had no overlap after dynamic reserve.

Therefore the power tree is adequate to continue Layout, but rail tolerance,
actual output span, settling/stability and temperature corners remain
fabrication/release blockers.

## 5. Power supervision and safe default behavior

Power qualification uses TPS3808 supervisors, LT3045/LT3094 PG signals and an
AON-powered TLV1701 negative-rail detector.

Nominal reviewed positive thresholds:

- 1V8 sense: about **1.7334 V**;
- 3V3 sense: about **3.13065 V**;
- 2.5 V reference sense: about **2.42595 V**;
- negative rail detector: approximately **-5.0 V**.

RAILS_OK falling clears the arm latch asynchronously. Restoring rails does not
automatically re-arm a previously asserted HIL_ARM; a new arm transition is
required. DAC reset has a hardware default asserted state.

The RTL heartbeat is progress-qualified rather than a free-running toggler:
completed Plant/I/O progress and a valid host lease are required. Default RTL
parameters currently target a WDI falling-edge interval of 5 ms, Plant/I/O
deadlines of 100 us and a 10 ms host lease. These are engineering defaults, not
a physical watchdog timing qualification.

**Procurement alert:** U501 is currently written in the schematic as
`TPS3430DRCR`, while TI currently exposes `TPS3430WDRCR` as the active
orderable 10-pin DRC device. The costed BOM marks this
`ORDERABLE_MPN_MISMATCH`; do not silently purchase/substitute until the exact
variant/timing/package equivalence is reviewed and the schematic/BOM are made
consistent.

## 6. AXU2CGB interface definition

### 6.1 J12 — 1.8 V Bank 66

J12 pins 3..34 are allocated as:

| Pins | Signals |
|---|---|
| 3..4 | DAC_SCLK, DAC_LDAC_N |
| 5..8 | DAC_CS0_N..DAC_CS3_N |
| 9..16 | DAC_SDIO0..DAC_SDIO7 |
| 17..20 | DAC_ALERT0_N..DAC_ALERT3_N |
| 21..28 | ADC_DOUT0..ADC_DOUT7 |
| 29..34 | ADC_SCLK, ADC_CS_N, ADC_SDI, ADC_CONVST, ADC_BUSY, ADC_RESET |

J12 physical pins 1/37/38 are GND, pin 2 is VCC5V, and pins 39/40 are carrier 3.3 V.
Those power pins are carrier facts, not permission to mix the 1.8 V GPIO bank with
3.3 V logic.

### 6.2 J15 — 3.3 V Bank 25/26

| Pins | Signals |
|---|---|
| 3..8 | PWM_UH, PWM_UL, PWM_VH, PWM_VL, PWM_WH, PWM_WL |
| 9..14 | ENC0_IO0..3, ENC0_DIR0..1 |
| 15..20 | ENC1_IO0..3, ENC1_DIR0..1 |
| 21..26 | AUX_IO0..AUX_IO5 |
| 27..29 | RS485_TX, RS485_RX, RS485_DE |
| 30..31 | MGMT_SCL, MGMT_SDA |
| 32..34 | HIL_ARM, HIL_WDI, HIL_FAULT_N |

The exact per-pin SoC-ball mapping is normative in
`hardware/carriers/axu2cgb/physical_pinout.csv`; the exact logical assignment
is normative in `assignments.csv`.

### 6.3 Mechanical registration

The pinned official ALINX DXF currently binds:

- host outline: **100 x 85 mm**;
- four mounting holes: 3.175 mm drill at
  (4.445,4.445), (95.5548,4.445), (4.445,80.5688), (95.5548,80.5688);
- J12 center: **(5.2578, 42.5069) mm**;
- J15 center: **(94.742, 42.5069) mm**;
- J12 pin 1: **(6.5278, 18.3769) mm**, right-column / low-y;
- J15 pin 1: **(93.4720, 66.6369) mm**, left-column / high-y.

Still open before a real mating footprint/stack can be released:

- exact AXU2CGB host connector MPN;
- exact mating connector MPN;
- mated stack height;
- carrier component/heatsink height keepouts.

Do not use a generic 2x20 footprint to create a manufacturable-looking board.

## 7. Analog outputs

Four AD3542RBCPZ16 provide eight 16-bit DAC channels. The exact CP-28-15
land pattern is source-bound to the official ADI evaluation-board evidence and
must not be replaced by a generic 4x4 QFN footprint.

The current analog output chain uses 52.3 Ohm starting-value source resistors and
ADG5412F protected switches. AO disconnect means **high impedance**, not a
guaranteed zero-voltage safe state. Cable load, DAC stability, settling,
calibration and actual DUT neutral behavior remain to be measured.

J5 is Phoenix 1844294, 10 positions: AO0..AO7 plus two signal grounds.
Those grounds are not chassis/PE.

## 8. Analog inputs

U801 is AD7606C-16BSTZ:

- AVCC = +5V0_DAC;
- VDRIVE = 1V8_D;
- internal reference selected;
- serial/software mode;
- CONFIG register 0x02 is written/read back before eight-DOUT operation;
- J801 provides eight low-energy single-ended channels;
- each input pair uses two 100 Ohm series legs and 1 nF differential capacitance.

This frontend is a **laboratory low-energy +/-10 V candidate**, not a 24 V PLC
input or qualified field-surge interface. The simplified 100 Ohm / 1 MOhm path
can contribute roughly 100 ppm uncalibrated gain error; source impedance,
anti-alias behavior, calibration, 16-bit accuracy and physical 1 MSPS operation
remain qualification items.

## 9. PWM, encoders, RS-485 and auxiliary I/O

Six PWM channels use a SN74LVC541A input buffer and hardware default pull-downs.

Each encoder port has clock and data differential pairs through THVD1450.
The intended SSI/BiSS roles are directional; generic `inout` at the carrier
contract does not mean arbitrary pin swapping. These ports do not supply encoder
power and are not a general ABZ / arbitrary 3-wire or 4-wire SPI interface.

RS-485 also uses THVD1450 and is safety-permit gated. 120 Ohm termination is
jumper-selectable and defaults open. AUX and I2C are 3.3 V logic. None of these
interfaces is isolated or suitable for direct motor-phase, gate-drive or 24 V PLC
connection.

## 10. Interlock and DUT permit limitations

J501 is a two-wire 3.3 V dry-contact service/interlock interface.
J701 uses AQY212GS as a floating normally-open DUT-permit contact.

For both two-wire contact semantics, a cross-line cable short can look like a
closed contact. Rev.B explicitly accepts this as a **non-safety residual risk**
for laboratory HIL use. These interfaces are not STO, redundant safety outputs
or cable-short fail-safe channels.

## 11. PCB Layout rules

Target layer roles:

| Layer | Role |
|---|---|
| L1 | components + signals |
| L2 | continuous GND reference |
| L3 | power distribution + slow signals |
| L4 | signals |
| L5 | continuous GND reference |
| L6 | components + signals |

Use continuous reference planes with functional zoning; do not hard-split
AGND/DGND. Fast or precision signals must never cross a reference-plane void.

Baseline non-fabricator-specific geometry:

- default clearance: 0.20 mm;
- default signal width: 0.20 mm;
- default via: 0.60 / 0.30 mm;
- copper-to-edge: 0.30 mm;
- VIN_RAW/VIN_PROT: pour or >=1.00 mm trace;
- medium-current rails: pour or >=0.50 mm trace.

Routing priority:

1. switcher hot loops and power current paths;
2. precision reference / DAC / ADC analog;
3. external differential pairs;
4. fast DAC/ADC digital groups;
5. safety handshake/control;
6. remaining low-speed signals.

Controlled-impedance width/gap is **not frozen** until a PCB fabricator stackup is
selected. Add a nearby GND stitching via at high-speed layer transitions and
place ESD return vias immediately beside the connector-side protection device.

## 12. Procurement and substitution policy

The complete grouped procurement snapshot is `bom/revb-costed.csv`.
It covers all 439 on-board physical refs: **431 populated + 8 DNP = 139 grouped
BOM lines**.

Pricing states mean:

- `EXACT_QUOTE`: source-bound MPN with a dated authorized-distributor/manufacturer
  small-quantity price.
- `EXACT_MPN_NO_LIVE_QUOTE`: exact MPN is source-bound but no executable authorized small-quantity quote is available at the snapshot; keep only a planning allowance and re-quote before PO.
- `CANDIDATE_QUOTE`: exact engineering candidate already present in qualification
  documents, but electrical/thermal qualification remains open.
- `ORDERABLE_MPN_MISMATCH`: purchasing identity is inconsistent with the schematic;
  release-blocking until resolved.
- `BUDGET_GENERIC`: value/package are fixed but manufacturer MPN is not; price is
  an engineering allowance, not a purchase approval.
- `DNP`: not fitted and zero stuffed cost.

Do not replace the following merely for cost or availability without explicit
design review: AD3542RBCPZ16 speed/grade/package, AD7606C-16 interface variant,
ADG5412F protected switch family, LT3045/LT3094/LT8330 analog power devices,
TPS259474L eFuse variant, ADR4525 grade, C105 exact land-pattern part, the reviewed
connector mechanical parts, or any part that changes a safety/default state.

## 13. First-board bring-up sequence

### 13.1 Before power

- verify PCB revision, assembly option and connector pin-1 orientation;
- inspect CP-28-15 DAC joints, exposed-pad packages, polarity parts and C105;
- measure resistance from input/rails to GND and investigate unexpected shorts;
- confirm J12/J15 mechanical registration before mating to AXU2CGB;
- leave DUT power stage and external AO/permit connections disconnected.

### 13.2 Power-only qualification

- use a current-limited laboratory supply at the low end of the 9–15 V input
  range; increase current limit deliberately while monitoring for abnormal draw;
- verify 3V3 AON and eFuse INPUT_OK behavior;
- verify 6V2_PRE, 3V3_D, 1V8_D, +5V0_DAC, +5V2_PVDD, -6V2_PRE, -5V2_PVSS and
  VREF_2V5 at the dedicated test points;
- check rail startup order, overshoot, ripple and power-down behavior with an
  oscilloscope before enabling analog outputs;
- verify RAILS_OK, arm latch and DAC_RESET_N fail closed.

Do not defeat U101's protection or raise the bench limit above the design intent
merely to make a failing board start.

### 13.3 Digital bring-up

- start DAC/ADC serial interfaces at the reviewed **10 MHz bring-up rate** before
  increasing clock rates;
- verify ADC CONFIG 0x02 write/readback, BUSY/CONVST and eight DOUT lanes;
- verify watchdog timing and explicit re-arm behavior;
- verify HIL_FAULT_N powered/unpowered behavior and absence of host backfeed;
- exercise PWM, encoder and RS-485 pins with low-energy fixtures only.

### 13.4 Analog bring-up

- keep AO physically disconnected from a real DUT;
- command midscale/known codes and measure all eight channels into high impedance;
- validate offset/gain/settling and switch disconnect behavior;
- feed known low-energy AI values and verify all eight ADC channels;
- only after this baseline, run load/cable/stability tests.

### 13.5 DUT connection

Connect a real DUT only after its adapter profile records neutral bias, permit
voltage/current/leakage, cable-open/cable-short behavior and maximum acceptable
disable time. Perform low-energy fault injection before any motor-power
closed-loop test.

## 14. Fabrication/release gates still open

Layout is authorized; fabrication and release are not. The following still need
raw evidence tied to the exact board/source revision:

- exact J12/J15 mating connector MPN, stack height and height keepouts;
- MLCC DC-bias/temperature/aging/RMS/ESR evidence;
- XAL L(I,T), AC/core/winding loss and startup/fault saturation;
- real DUT adapter thresholds, leakage and shutdown timing;
- partial-power/backfeed;
- assembled-board thermal;
- low-energy fault-injection fixture;
- Vivado raw I/O DRC plus functional STA/CDC;
- EMC, power-down, fault injection and FOC physical closed-loop acceptance.

Passing ERC, SPICE, unit tests or PCB DRC is not a manufacturing or functional
safety certificate.

## 15. Related detailed evidence

- Power equations: `docs/design/native-power-stage-calculations.md`
- Power supervision: `docs/design/native-power-supervision.md`
- Electrical verification: `sim/power/README.md`
- ADC/PHY: `docs/review/revb-peripherals/README.md`
- Safety chain: `docs/review/revb-safety/README.md`
- Layout: `docs/review/revb-layout/README.md`
- Procurement/cost methodology: `docs/design/revb-procurement-and-cost.md`

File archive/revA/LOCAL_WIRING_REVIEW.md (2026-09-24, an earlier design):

> Historical review log. Current final results and limitations: [2026-09-24 PR18 handoff](validation/2026-09-24-pr18-handoff.md). Earlier label/ERC statements below are superseded.

# Rev.A local-wiring repair / PR #18

## Scope and authority

Work is confined to `archive/revA/` on `fix/reva-kicad-connectivity`.
The native `.kicad_sch` files remain editable design artifacts. Rev.A remains
PRELIMINARY and is not a fabrication target. No package, power-stage value,
FPGA pin-plan, or PCB release gate is frozen by this drawing repair.

Starting PR head: `af31036415cdcb8abf51eaa24d6f89be6f098708`.
Electrical intent reference: the archived schematic at main
`3f052eb85ff04d3c54995e66268e03b74d2771f9`, before the readability edits.

## Confirmed findings

1. A global label was used on almost every pin, including divider midpoints,
   compensation nodes, and DAC-local feedback nets. Merely replacing these
   with local labels would leave the circuit just as fragmented.
2. The starting `01_power_entry.kicad_sch` has U1 at (165.1,85.09), but wires
   for IN/OVLO/PGTH and OUT/DVDT/ILM still use the old symbol coordinates.
   C4 and C5 each have a first-pin wire at x=264.16 while their bodies are at
   x=215.9 (first pin x=210.82). A label-name/count check does not catch this.
3. The intended U1 mapping in the pre-repair archive is:
   5=VIN_RAW, 1=UVLO_NODE, 2=OVLO_NODE, 4=PGTH_NODE, 8=GND,
   6=12V_PROT, 3=EFUSE_PG, 7=DVDT_NODE, 9=ILIM_NODE, 10=ITIMER_NODE.
4. The runtime has no KiCad executable and cannot resolve github.com for a
   git clone. Repository changes are published through the GitHub connector.
   Geometry/graph tests must not be reported as native KiCad ERC or export.

## Drawing policy

- Connect nearby components with actual orthogonal wires and junctions.
- Use at most one local net name on a continuously wired internal node.
- Use global labels only for actual cross-sheet nets; shared power rails may
  have one entry per physically separate functional block when this prevents
  unreadable sheet-spanning power wires.
- A ground power symbol is a deliberate shared power connection, not a
  substitute for wiring a regulator's feedback or compensation network.
- Preserve component references, values, pin numbers, NC intent and the
  archived electrical topology. Identify corrections to broken PR geometry
  explicitly instead of claiming equivalence to an already broken drawing.
- Do not overwrite hand edits via automatic regeneration on opening a project.

## Stages (each schematic stage receives its own commit)

- [x] Audit the current PR and record scope / detached-pin regression.
- [ ] Rewire power entry: input filter, eFuse, UV/OV divider, PG divider,
      timing/current-limit components and output capacitors.
- [ ] Rewire analog power: positive LDOs, negative preregulator/LDO, reference.
- [ ] Rewire digital power: sequencing, buck output/feedback/compensation.
- [ ] Rewire HIL-Link and FPGA-local configuration / hardware-safe circuits.
- [ ] Rewire the four DACs: feedback/CFB/output resistors and decoupling.
- [ ] Run whole-hierarchy scope/net/NC checks; record native-tool limitations.

## Validation requirements

A successful S-expression parse alone is insufficient. Check every physical
pin against a reviewed net contract, distinguish NC from dangling pins, detect
conflicting names, check local-vs-global scope, and inspect the drawing geometry.
Native KiCad hierarchy load, netlist export and ERC remain separate acceptance
checks and must be reported with the actual tool version and output when run.

## 2026-09-24 global-label scope audit

PR #18 now applies a strict scope rule to the native Rev.A hierarchy:

- a sheet-local node is represented by a local label or continuous wiring, not a
  global label;
- an actual cross-sheet net keeps exactly one explicit global label per sheet;
- additional occurrences of that same cross-sheet net on the sheet are local
  labels unless a power symbol provides the connection;
- pages 01/02/04 intentionally use `power:GND` symbols, so they do not require
  a separate explicit `GND` global-label object.

Current explicit global/local label counts after the scope cleanup are:

| Sheet | Global | Local |
| --- | ---: | ---: |
| 01_POWER_ENTRY | 3 | 7 |
| 02_ANALOG_POWER | 7 | 13 |
| 03_DIGITAL_POWER | 10 | 172 |
| 04_AXU_HIL_LINK | 25 | 10 |
| 05_IO_FPGA | 50 | 68 |
| 06_DAC_0_3 | 21 | 19 |
| 07_DAC_4_7 | 21 | 79 |

Structural audit of all seven child schematics at the current branch state:

- zero sheet-local nets remain as explicit global labels;
- zero duplicate explicit global labels remain for the same net on one sheet;
- every baseline cross-sheet net retains one global entry on each participating
  sheet, except GND where the reviewed pages use KiCad power symbols;
- S-expression parentheses/strings are balanced on all seven files;
- no duplicate schematic UUID was found in any child sheet;
- all explicit `no_connect` records use the valid two-coordinate KiCad form.

The three pages called out for the remaining label cleanup were committed
independently:

- `03_digital_power.kicad_sch`: `b26e38a`;
- `05_io_fpga.kicad_sch`: `2b935cd`;
- `07_dac_4_7.kicad_sch`: `62072ba`.

The whole-hierarchy audit also found and removed the remaining duplicate
cross-sheet rail entries in analog power and DAC0-3 in follow-up commits
`cc6dac6` and `54fbe28`.

GitHub Actions currently cannot serve as the Rev.A native KiCad gate because the
repository-level Rev.B workflow intentionally rejects any modification of the
historical snapshot with `historical snapshot bytes changed` before reaching
its KiCad stages. Unit/mutation regressions complete first; a native KiCad
open/export/ERC still has to be run from a workstation for final graphical and
electrical acceptance of this archive repair.

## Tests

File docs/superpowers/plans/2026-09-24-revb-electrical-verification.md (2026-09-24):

# Rev.B Electrical Design Verification — implementation ledger

**Goal:** execute the user-approved calculation → simulation → component-selection verification stage against native Rev.B, without changing board topology or starting layout.
**Base:** main bc08c999843a1eacb0794f673f65e532ac1148c1 (PR19 merged).
**Architecture:** read native KiCad component values; keep assumptions/provenance separate; run portable, explicitly non-vendor SPICE power-stage/envelope cases in ngspice; prepare LTspice vendor workflows without redistributing vendor models. No simulator result alone may release hardware.
**Execution:** inline, section-by-section remote commits. The continuation recovered an isolated local checkout and a hash-identified ngspice-42 executable from CI, then ran local numerical/TDD regressions. Full matrices also run in read-only GitHub Actions. Native KiCad export/ERC evidence comes from CI; local checks consume byte-matched native source/netlists.

## Constraints
- Single SoC, SoM UNBOUND, archive unchanged, no ADC/PHY expansion or PCB layout.
- Do not regenerate native schematics, alter feedback values to make checks green, or rewrite release gates.
- Analytical screening, behavioral/power-stage SPICE, vendor-macro simulation and bench evidence are distinct.
- Missing model/license/curve means BLOCKED, not assumed PASS. Exact source/deck/model hashes accompany results.
- Preserve original GitHub↔Notion tests; read-only CI.

## Tasks / commit checkpoints
- [x] A: RED tests, then native-value-bound worst-case / thermal / MLCC / magnetic screening.
- [x] B: runnable ngspice startup, load-step and shutdown benches; strict measure parser; raw logs, waveform data, hash manifest.
- [x] C: LTspice vendor acquisition/bench instructions, exact inductor candidates and capacitor derating evidence requirements.
- [x] D: run existing + new tests, inspect actual simulation outputs, publish reviewed results and PR; keep layout blocked.

## Acceptance
Changing a used native resistor/inductor must change the derived calculations, not silently leave stale constants. Reject invalid/nonfinite inputs, missing measures, missing ngspice and absent DC-bias evidence. Test the known +/-5.2V full-temperature tolerance issue without changing the schematic. A passing automation job means the analysis ran, not that the electrical design passed. '--strict-design' must fail while blockers exist.

## Review focus
Thermal Rtheta/efficiency assumptions are not package guarantees. AP63201 has only typical oscillator frequency: 450kHz sensitivity is not a guaranteed minimum. Cuk switch carries the sum of two currents and its 1A rating is not output capability. Initial SET accuracy is not full-temperature accuracy. Power-stage open-loop results do not validate chip control/stability/current limiting. Vendor IP is not committed or uploaded as an artifact.

## Continuation rulings and evidence
- A-D above mean screening infrastructure, source-backed candidates, preparation workflows and reviewed automation, NOT completed physical qualification.
- Preserve RSET and native topology. Full-condition DAC limits are a real unresolved design issue; do not tune values merely to pass a check.
- Fix numerical clock edges rather than relaxing the 0.001 duty gate; verify against real ngspice and a half-timestep case.
- Individual Cuk inductor current reversal is not alone the DCM criterion. Check diode-current sum, flag invalid CCM points and retain open-loop output failures.
- Candidate-specific +/-20% capacitor tolerance must not inherit the generic +/-10% scenario. Exact part curves and original-file/CSV hashes are separate evidence.
- A killed/partial/stale simulator run cannot qualify as complete; all 25 native-bound cases and their log/artifact integrity must be checked.
- The local git history is an isolated test snapshot. Upstream commit identities are recorded in the review checkpoint, not substituted by local SHAs.
- Full repository 123/123 tests and synchronization 15/15 tests passed. Native XML came from a separately hashed CI artifact after 37 source files matched exactly.

Detailed commands, model limitations and curve/vendor workflow:
`sim/power/README.md`. Immutable reviewed run identities and open findings:
`docs/review/revb-edv/README.md`.

### Remaining qualification gates (not completed)
- [ ] Resolve DAC full-condition supply/headroom conflict.
- [ ] Execute exact manufacturer closed-loop models, including light-load/short-circuit mode and stability review.
- [ ] Obtain actual MLCC DC-bias/lifetime evidence, close C105 MPN, C410 lifecycle and Cuk effective-C targets.
- [ ] Close magnetic AC/core loss, temperature/current derating and footprint/height verification.
- [ ] Close input protection energy, partial-power backfeed and shutdown/discharge behavior.
- [ ] Independent board thermal/transient measurements; separate layout authorization.

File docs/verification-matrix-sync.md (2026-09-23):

# GitHub ↔ Notion Verification Matrix sync

Tracked Issues and PRs carry explicit V&V metadata. The sync key is the pair
`REQ-ID + TC-ID`.

The design deliberately separates **GitHub lifecycle state** from **engineering
verification state**:

- Issue closed / PR merged never implies `PASS`.
- A new PR head (`synchronize`) makes PR-bound evidence stale and resets the
  Matrix verdict to `NOT RUN / Ready` until evidence is explicitly refreshed.
- Closing or merging a PR does not re-apply an older body verdict after a new
  commit invalidated it.

## Metadata contract

Supported fields:

- `REQ-ID`
- `TC-ID`
- `Knowledge Node URL`
- `Requirement`
- `Test Case`
- `Verification Level`
- `Acceptance Criteria`
- `Evidence Path`
- `Evidence URL`
- `Evidence Date` (`YYYY-MM-DD`)
- `Bench / DUT`
- `HW Revision`
- `FW SHA`
- `Bitstream`
- `Result`
- `Verification Status`

`Result` is one of `PASS`, `FAIL`, `PARTIAL`, `BLOCKED`, `NOT RUN`.

## Field ownership

GitHub automation owns only machine-oriented Matrix fields:

- GitHub Issue/PR URL, number and lifecycle state
- Git SHA
- FW SHA
- Bitstream
- HW Revision
- Evidence Path / Evidence URL / Evidence Date
- Result / Verification Status when explicitly present in trusted metadata
- Evidence freshness and Evidence Git SHA
- Last Synced / Sync Contract

Human/test-report fields such as `Evidence` and the curated
`Commit/FW/Bitstream` summary are **not overwritten** by automation.

For an existing Matrix row, the legacy `Issue/PR` URL is also left unchanged;
dedicated `GitHub Issue` and `GitHub PR` fields preserve both links instead of
letting Issue and PR events overwrite each other.

## Evidence freshness

For PR-backed evidence:

- explicit `PASS` / `FAIL` / `PARTIAL` binds `Evidence Git SHA` to the current
  PR head and marks freshness `current`;
- a later `synchronize` event updates `Git SHA`, marks evidence `stale`, and
  resets the verdict to `NOT RUN / Ready`;
- a later PR close/merge updates only lifecycle fields and cannot silently
  restore the stale verdict.

This enforces the rule that evidence from an older commit is not inherited by
a newer commit.

## Repository / organization configuration

Configure:

- secret `NOTION_TOKEN`: Notion integration token with access to the Engineering
  Evidence / Verification Matrix;
- variable `NOTION_VERIFICATION_DATA_SOURCE_ID`: Matrix data-source UUID.

Prefer organization-level secret/variable scoped to these four repositories so
the same contract is configured once:

- `magic-alt/hil_lab`
- `magic-alt/igh-lab`
- `magic-alt/servo_host`
- `magic-alt/servoHIL`

Share the Matrix and related Knowledge Node database with the Notion
integration. The workflow uses Notion API version `2026-03-11`.

If either setting is missing, contract validation still runs but Notion writes
are skipped.

## Security

The workflow uses `pull_request_target` so metadata can be validated for fork
PRs. It always checks out the trusted default branch and never checks out or
executes PR code.

Notion credentials and GitHub write-back are used only for:

- same-repository PRs; or
- `OWNER` / `MEMBER` / `COLLABORATOR` authored Issues/PRs.

Untrusted external Issues/PRs are validation-only.

## Upsert and reverse link

Exactly one Matrix row is matched by `REQ-ID + TC-ID`.

- one match: update it;
- no match: create only when `Knowledge Node URL` is present;
- duplicate matches: fail closed.

After a successful Notion write, the workflow creates or updates a single bot
comment containing the Matrix record URL. This gives direct navigation in both
directions without making Notion edits mutate engineering state back into
GitHub.

## Recommended workflow

1. Create the Matrix Requirement/Test Case first (or provide Knowledge Node URL
   for first-write creation).
2. Put the same `REQ-ID / TC-ID` in the Issue and implementing PR.
3. Let CI/HIL/physical tests produce versioned evidence.
4. Update `Evidence Path`, configuration fields and explicit `Result`.
5. If the PR head changes, re-run the evidence before restoring `PASS`.

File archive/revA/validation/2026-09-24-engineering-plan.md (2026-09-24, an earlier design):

# Rev.A native schematic completion plan — PR #18

**Goal:** Finish the native Rev.A schematic connectivity/readability repair on `fix/reva-kicad-connectivity`, following the user's KiCad engineering rules, without converting Rev.A into Rev.B or authorizing fabrication.

**Architecture:** Preserve the existing power / HIL-Link / local FPGA / four-DAC partition. Wire functional circuits continuously inside each sheet. Represent inter-sheet signal interfaces with hierarchical labels and sheet pins; reserve global connections for reviewed shared rails / system safety exceptions. Keep all native files manually editable.

**Tech stack:** Native KiCad schematic/project files, KiCad CLI netlist/ERC/SVG export, Python standard-library checks, GitHub Actions read-only verification.

**Specification:** https://app.notion.com/p/02-2-KiCad-PCB-Layout-3e55ebb6169681528093c01b2f551315 (read 2026-09-24), especially sections 2, 3.2–3.7 and 3.11.

## Baseline and constraints

- Starting PR head: `f351fc7b4ff515eacee660fb2ed28ccd0c0b2c7a`.
- Latest main checked at start: `8a1d00a06bd3dac5758fd14a551b9f27e5e5358e`.
- GitHub comparison reports ahead 24 / behind 0; main is already an ancestor. Do not manufacture an unnecessary merge or rewrite history.
- Native project: `archive/revA/snapshot/hardware/kicad/revA/servohil_io_revA.kicad_pro`.
- No PCB layout, package/pin-plan freeze, regulator component qualification, or hardware safety PASS is implied by this work.
- Preserve references, component values, pin numbers and explicit NC intent unless a separately documented electrical correction is required.
- Preserve existing Rev.B work. Do not weaken its electrical or fabrication gates to make archive-only edits pass.
- The current interactive container has neither KiCad nor direct GitHub DNS access. Connector writes are real Git commits; structural checks are not native ERC. Attempt an independent native Rev.A validation job and report its actual outcome.

## Review focus

1. A moved symbol or passive can leave its wire endpoint at the old coordinate: check pin-to-net membership, not label counts.
2. Replacing a global label with a local label may change scope or merely disguise a fragmented circuit: verify connectivity and review exported pages.
3. Hierarchical interface changes can split existing shared nets: compare physical component-pin groups across the full hierarchy.
4. A clean ERC may reflect disabled severity/exclusions: inspect project rules and report all exceptions.
5. The historical archive checksum gate must not prevent native Rev.A checking, nor be silently disabled for other changes.

## Work packages — separate commits

- [x] Read current PR metadata, main relationship, root README, architecture, core BOM, and engineering rules; record baseline.
- [ ] Establish an independent read-only Rev.A native netlist/ERC/render gate; collect the starting failures.
- [ ] Repair digital-power continuous regulator loops and local support circuits; preserve and test physical pin contracts.
- [ ] Complete FPGA-local configuration/safety support and the remaining DAC page wiring; keep repeated channels visually consistent.
- [ ] Audit all power/DAC sheets for accidental shorts, detached pins, NC changes, duplicate identifiers and property collisions.
- [ ] Make top-level inter-sheet interfaces explicit, with verified hierarchical signal connectivity and documented global exceptions.
- [ ] Run native hierarchy export/ERC plus regression/equivalence checks; inspect rendered pages, then update PR description and completion evidence.

## Reproducible native baseline

From repository root (KiCad installed):

```sh
mkdir -p build/reva
native=archive/revA/snapshot/hardware/kicad/revA
kicad-cli version
kicad-cli sch export netlist --format kicadxml -o build/reva/netlist.xml "$native/servohil_io_revA.kicad_sch"
kicad-cli sch erc --format json --severity-all --exit-code-violations -o build/reva/erc.json "$native/servohil_io_revA.kicad_sch"
kicad-cli sch export svg -o build/reva/svg/ "$native/servohil_io_revA.kicad_sch"
```

An ERC process exit, exported XML, and visual review are separate observations. Never infer electrical completion from successful serialization, historical results, or a workflow that skipped its native steps.

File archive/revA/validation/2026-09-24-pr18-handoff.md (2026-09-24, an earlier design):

# PR #18 — Rev.A 原理图修复交付记录

## 范围与状态

分支：`fix/reva-kicad-connectivity`，继续使用 PR #18，没有另开实现分支，也没有合并 PR。
本轮基于已经包含 `main@8a1d00a06bd3dac5758fd14a551b9f27e5e5358e` 的分支。
用户指定 `03_digital_power.kicad_sch`、`05_io_fpga.kicad_sch`；为保证跨页网络不断开，
同步修改了根页和所有对端页的层次接口。Rev.B 原理图、物料值、PCB 与门禁没有修改。

执行约束来自 Notion《02.2｜KiCad 原理图与 PCB Layout 工程准则》：
同页优先真实导线，跨页显式层次接口；网表等价与图面可读性分别验收；不通过关闭 ERC 掩盖问题。

## 分阶段原生文件提交

| 阶段 | 已推送的原生修改提交 | 内容 |
|---|---|---|
| 1：数字电源接口 | `615e1f18f09db599c783d7cc2c13f9410e251f5e` | 03 页 9 个剩余 Global Label 及对端迁移为层次接口；保留已连好的电源、反馈、补偿回路 |
| 2：FPGA 与完整层次连接 | `9e6f1331e24bbc65cfa14ed3631e14e5bfd85512` | QSPI、JTAG、时钟、配置上拉、看门狗/复位链真实连线；全工程 Global Label 清零，133 个父子层次引脚对应 |
| 3：库、图面与完整 ERC | `846ce4a285e4c31f3840e6058e376be4b8a25a84` | 修正顶层标签短线尾、端口文字、离网格点与图框冲突；外部符号库与图内副本一致，ERC 全部通过 |

这三项是已经进入 Git 的 `.kicad_sch/.kicad_sym` 修改，不只是编辑脚本或待执行计划。
测试、定位修复、CI 与交付记录另有小提交。一次性重画脚本不应作为日常编辑入口；交付后移除临时写仓库工作流及重画脚本，Git 历史保留过程。

## 最终标签统计

| 子页 | Global Label | Hierarchical Label | Local Label |
|---|---:|---:|---:|
| 01_POWER_ENTRY | 0 | 3 | 7 |
| 02_ANALOG_POWER | 0 | 7 | 13 |
| 03_DIGITAL_POWER | 0 | 9 | 50 |
| 04_AXU_HIL_LINK | 0 | 25 | 10 |
| 05_IO_FPGA | 0 | 49 | 25 |
| 06_DAC_0_3 | 0 | 20 | 19 |
| 07_DAC_4_7 | 0 | 20 | 29 |

根页：0 个 Global Label，133 个匹配 Sheet Pin；HIL-Link 与 DAC 控制/数据在根页实际连线。
根页普通标签用于电源扇出及原有模拟输出接口。

本轮 PR 起点：03 页 9 个 Global Label；05 页 50 个 Global Label、64 个 Local Label。
05 页 Local Label 由 64 降到 25；减少的是通过标签拼接的孤立功能块，不是删掉有用的信号标识。
03 页保留的普通标签主要用于给真实连续回路命名，以及远距离电源/监测取样点。
`GND` 电源符号仍具有全局网络语义；“Global Label 为 0”不表示工程没有共享地。

## 独立验证证据

验证原生源提交：`846ce4a285e4c31f3840e6058e376be4b8a25a84`。
KiCad：10.0.6；系统符号库正确安装并配置；ngspice：42。

- **23/23** Rev.A 层次、真实连线、几何、符号库回归通过，没有跳过。
- **133/133** Sheet Pin 位于正确边界、正确方向、真实导线顶点，父子接口完整匹配。
- **513/513** 重点页物理 pin/net 契约通过。
- 全工程独立 KiCad XML 与原始 `main` 冻结连接分组完全一致：**191 个物理器件、209 个网络、716 个引脚**。
- 完整 ERC：**0 errors / 0 warnings / 0 exclusions**，使用 `--severity-all --exit-code-violations`。
- **123/123** 仓库单元测试通过，使用真实 Rev.B 原生网表和 ngspice，没有跳过。
- **15/15** verification-sync 单元测试通过。
- 八页由 KiCad 原生导出 SVG；重点人工查看根页、数字电源、FPGA 页的导线、文字、图框、去耦归属和接口排列。
- 原生文件验证后工作树没有未提交差异。

阶段 3 Actions：
https://github.com/magic-alt/servoHIL/actions/runs/35982150393

对应 `reva-final-native-review` artifact ID：`10800767145`。
其中包含 `source_commit.txt`、`netlist.xml`、`equivalence.json`、`pin-contract.json`、
`erc.json`、`erc-summary.json`、测试日志、八页 SVG、完整源文件及 Git bundle。
Actions artifact 有保存期限，复核资料应另行归档。

## 符号库处理说明

保留原有物理器件编号、数值、封装、引脚号、引脚名和电气类型。
FPGA/数字电源可读性变体提供匹配的项目符号库，没有假称变成功能完整的封装符号。
J12_40、AD3542R、LTC7149 已审阅图内定义同步到外部项目库，更新前校验引脚签名一致。

原有 GND 符号的隐藏引脚名是 `GND`；KiCad 10.0.6 安装库对应引脚名为空字符串，
因此不能把两份定义直接声明为完全相同。此次将原始 GND 定义完整复制到
`ServoHILGround:GND` 项目库，保留 `power_in`、全局地语义、原图形与原连接坐标；
没有为了消除告警把引脚类型改成 passive。回归测试对完整原定义执行 SHA-256 校验。

## 保留的限制与独立失败项

**原理图连接/可读性修复通过，不代表 Rev.A 电气产品开发完成。**

1. U10 仍是 FUNCTIONAL_PRELAYOUT，无 FGG484 球位冻结；C230/C231/C232 只是 bulk，不代表逐脚去耦完成。
2. 电源、watchdog、level translator 等仍含功能抽象；器件选型、补偿、启动、MLCC 降容、热及安全实测未获批准。
3. 原始归档的两页 DAC 共用 `AO0_IA/AO1_IB/AO2_IC/AO3_VBUS`。本次按原始连接契约保留，未批准该输出共享方式用于产品。
4. `layout_allowed` 仍为 false，没有布局、布线、生产或实机功能验收结论。
5. **仓库 `hardware-structure` 仍失败**：`tools/check_revb_repository.py` 要求历史快照树完全不变，
   因这次明确要求的 Rev.A 修复而报 `historical snapshot bytes changed`。
   原始树校验未关闭、未重新指定基准，Rev.B 门禁没有放宽。不能将本轮 native 检查 PASS 说成整个 PR 所有 CI 已通过。

## 复核与继续编辑

直接打开：

```text
archive/revA/snapshot/hardware/kicad/revA/servohil_io_revA.kicad_pro
```

必须使用完整工程、根页、七个子页、所有项目 `.kicad_sym` 与 `sym-lib-table`；
不要只替换两张子页，否则旧根页缺少对应层次引脚。

在仓库根目录只读验证：

```sh
python -m unittest discover -s archive/revA/validation -p 'test*.py' -v
python archive/revA/validation/check_sheet_pin_sides.py
mkdir -p build/reva
kicad-cli sch export netlist --format kicadxml -o build/reva/netlist.xml archive/revA/snapshot/hardware/kicad/revA/servohil_io_revA.kicad_sch
python archive/revA/validation/check_pin_contract.py build/reva/netlist.xml
kicad-cli sch erc --format json --severity-all --exit-code-violations -o build/reva/erc.json archive/revA/snapshot/hardware/kicad/revA/servohil_io_revA.kicad_sch
```

常规 `reva-native-schematic` CI 只读检查、导出与留存证据，不修改或重新生成原理图。
后续有意修改真实电路时应独立审查并更新相应设计契约，不能简单删除等价检查。

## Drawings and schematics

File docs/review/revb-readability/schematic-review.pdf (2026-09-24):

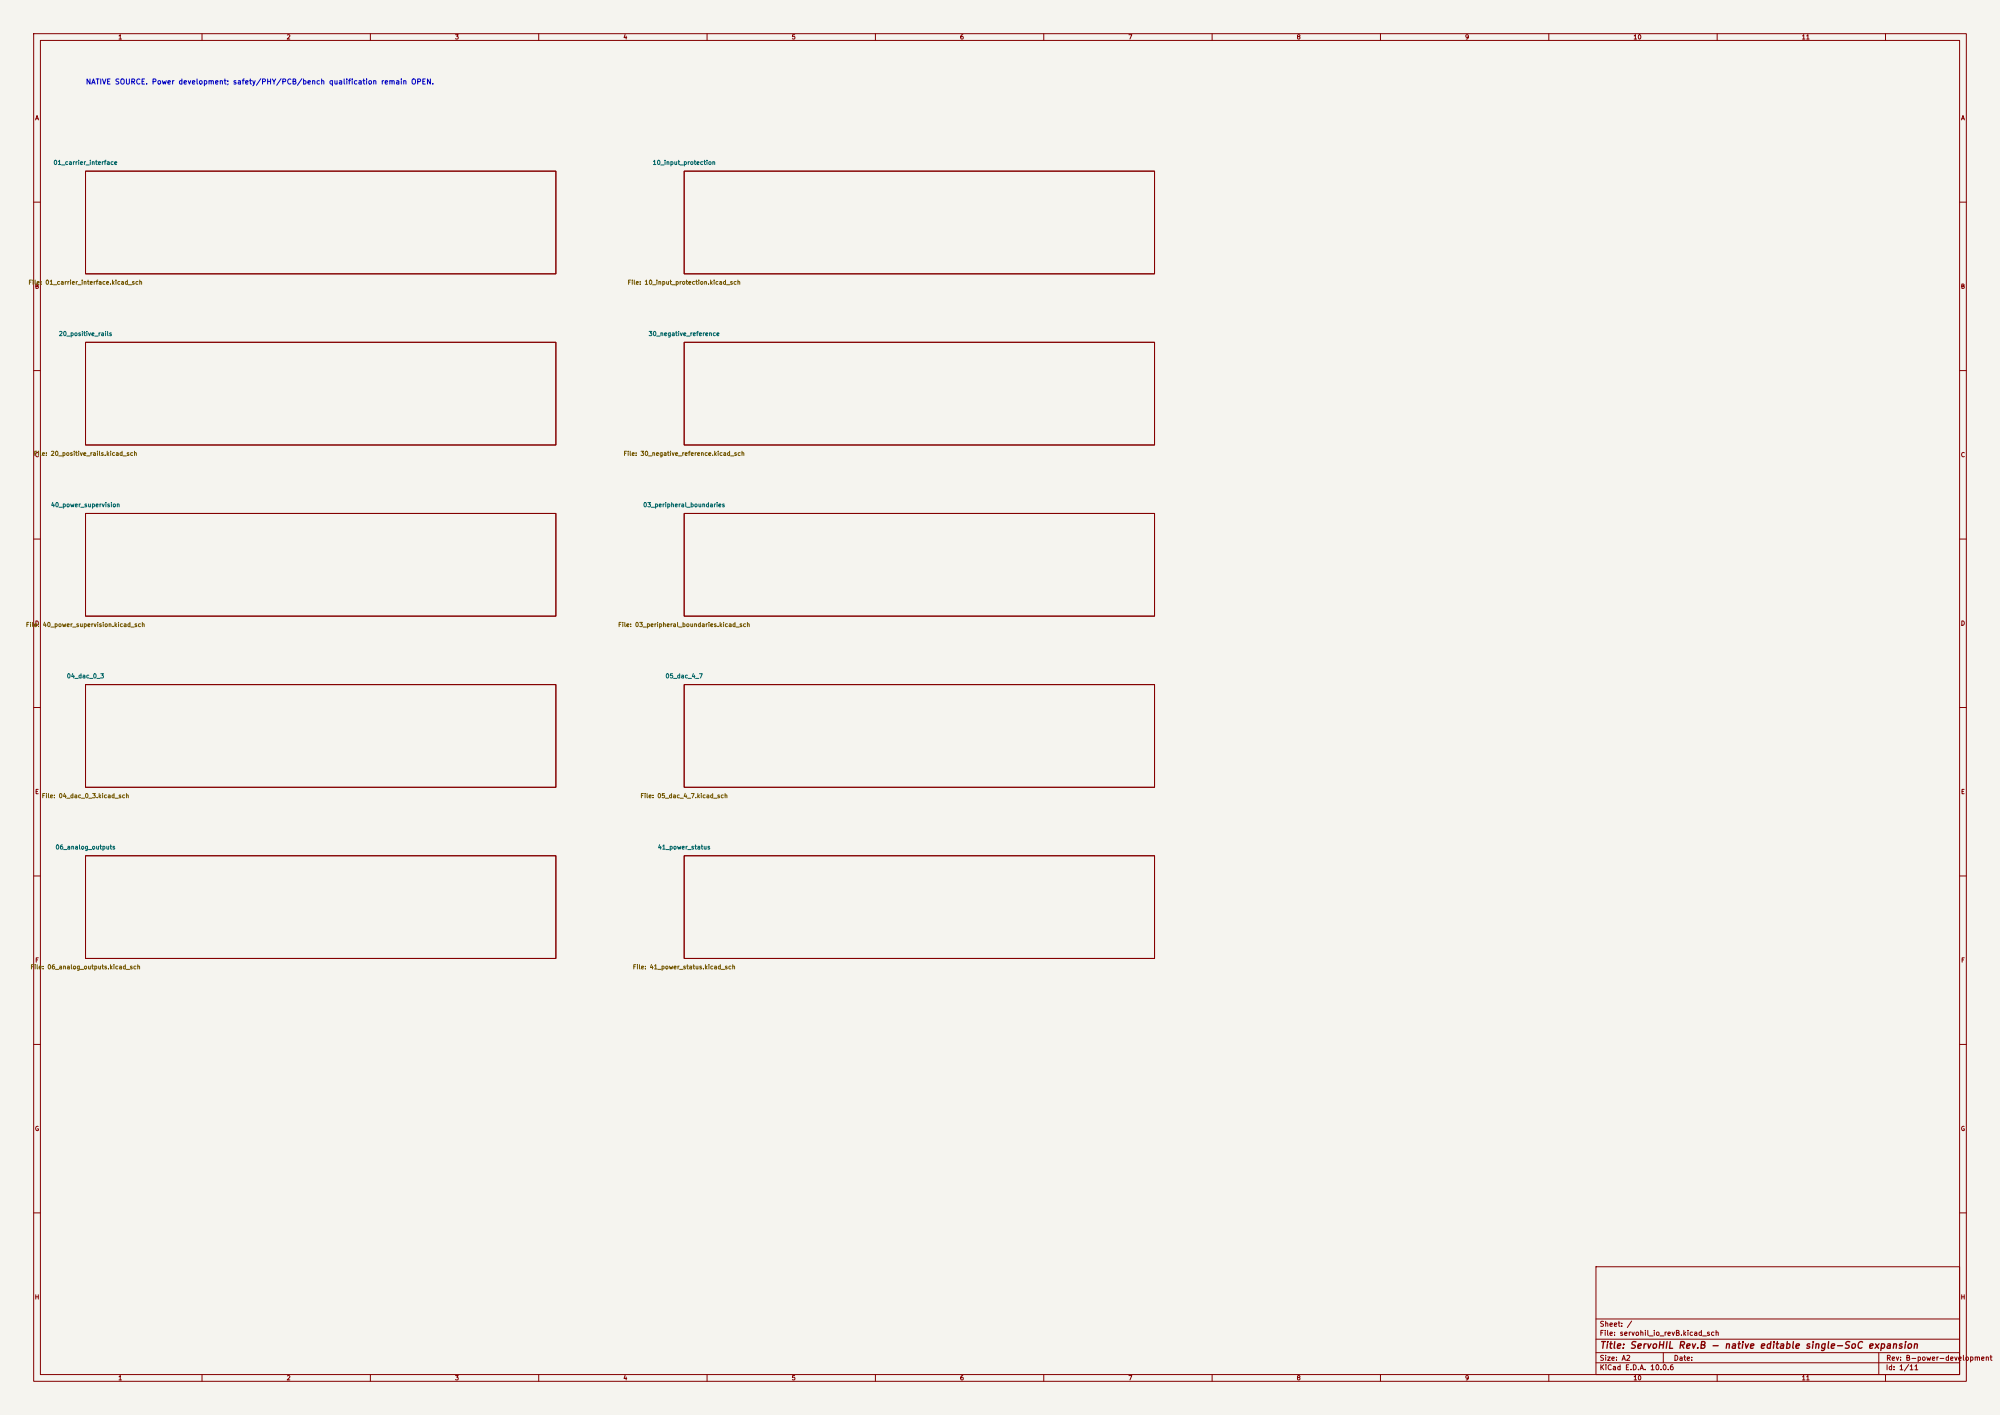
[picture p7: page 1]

NATIVE SOURCE. Power development; safety/PHY/PCB/bench qualification remain OPEN.

Sheet: /
File: servohil_io_revB.kicad_sch
Title: ServoHIL Rev.B - native editable single-SoC expansion
KiCad E.D.A. 10.0.6

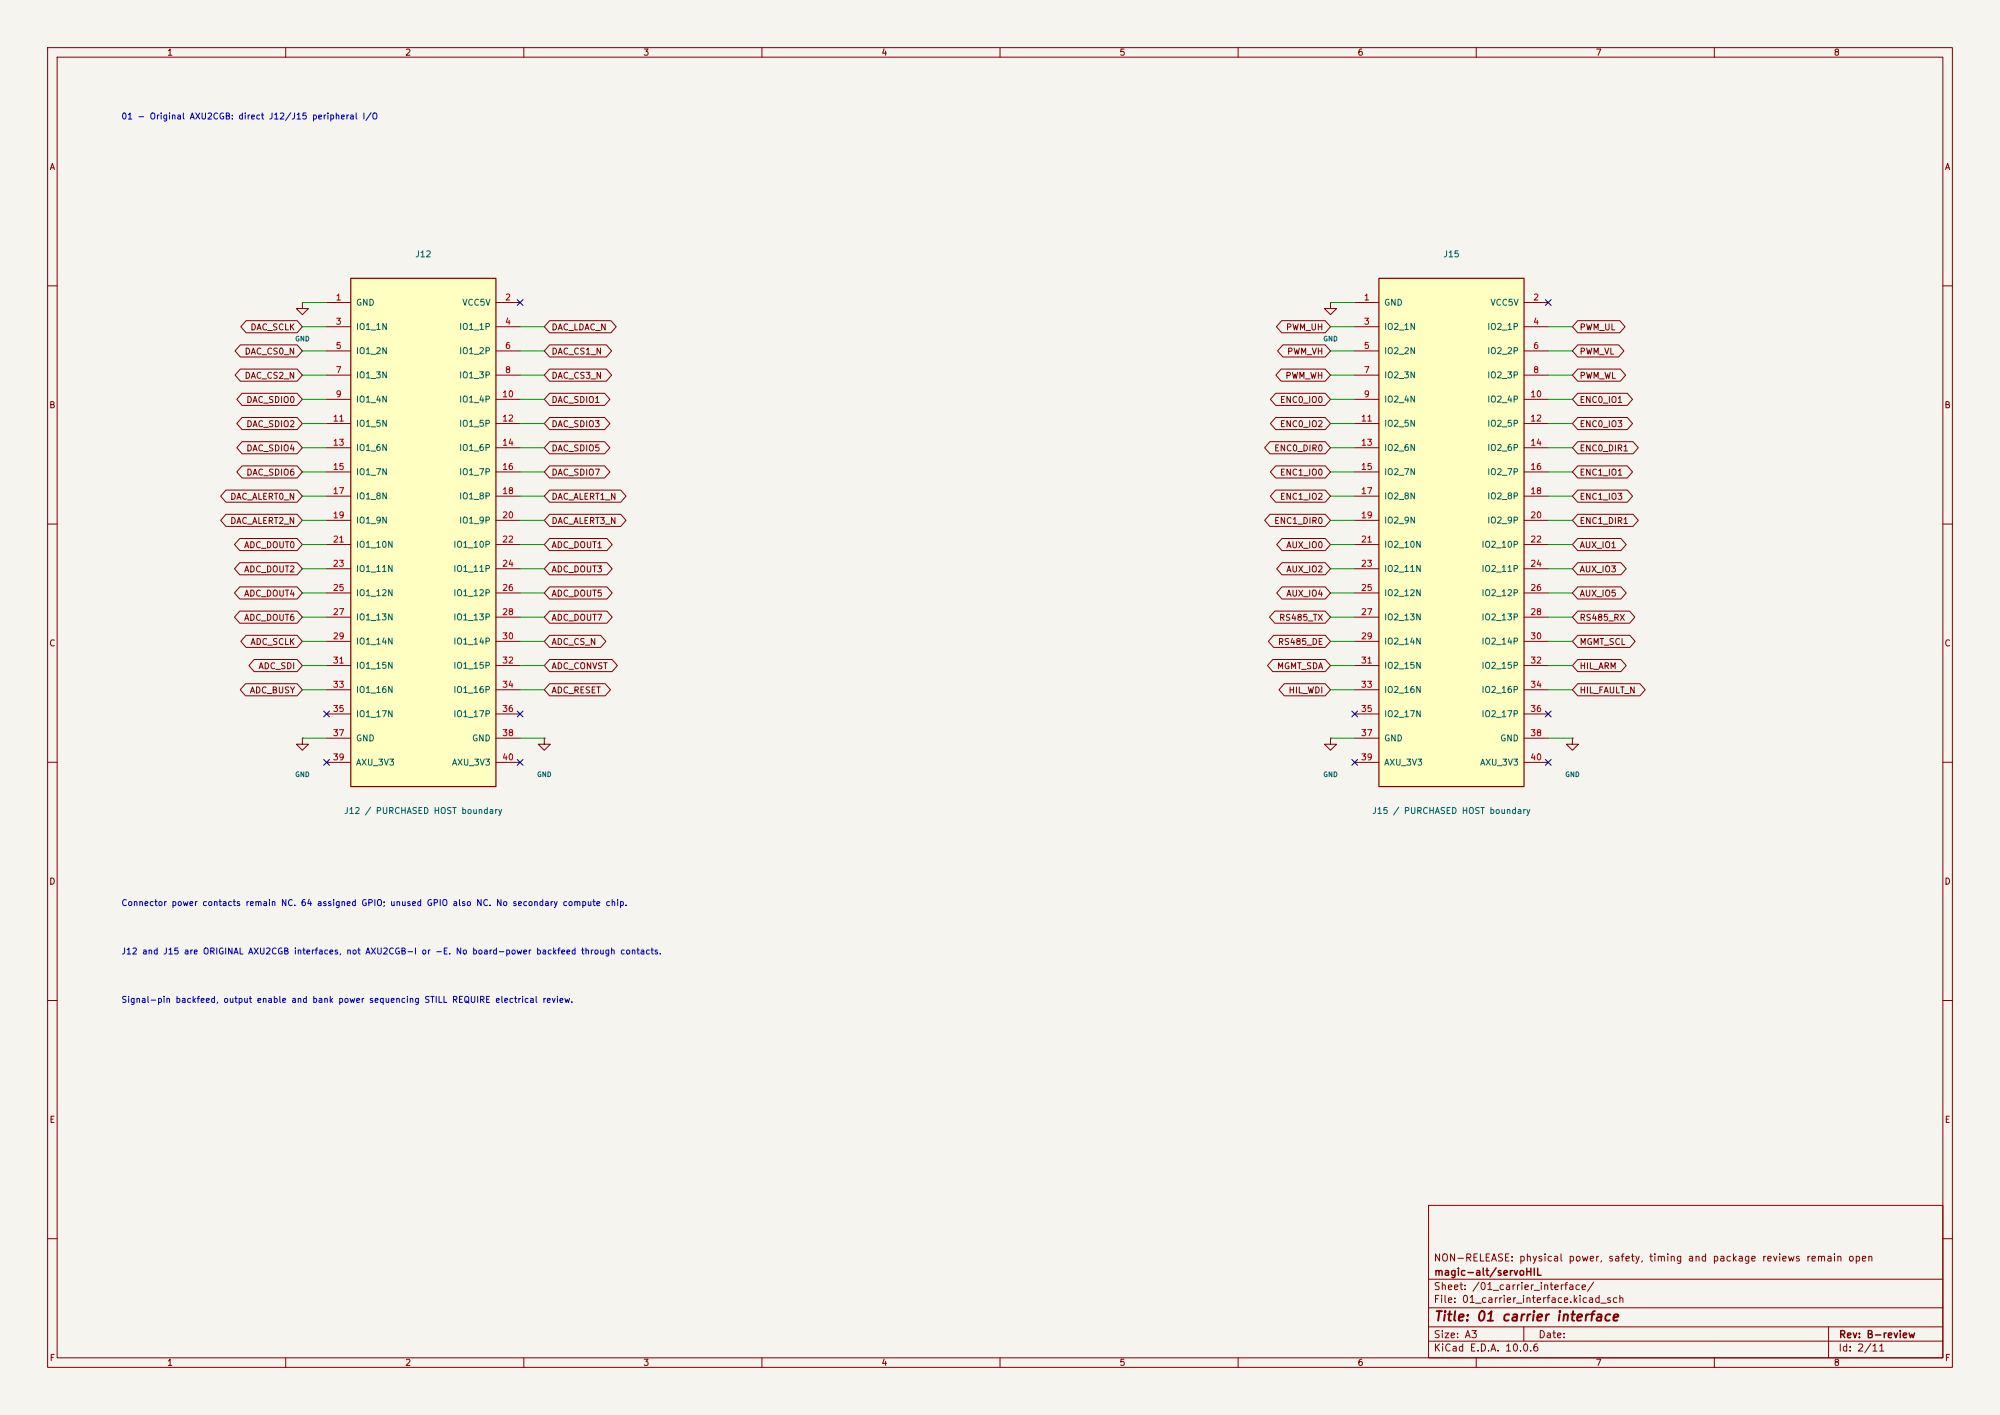
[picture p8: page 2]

Connector power contacts remain NC. 64 assigned GPIO; unused GPIO also NC. No secondary compute chip. J12 and J15 are ORIGINAL AXU2CGB interfaces, not AXU2CGB-I or -E. No board-power backfeed through contacts. Signal-pin backfeed, output enable and bank power sequencing STILL REQUIRE electrical review.

NON-RELEASE: physical power, safety, timing and package reviews remain open
magic-alt/servoHIL
Sheet: /01_carrier_interface/
File: 01_carrier_interface.kicad_sch
Title: 01 carrier interface

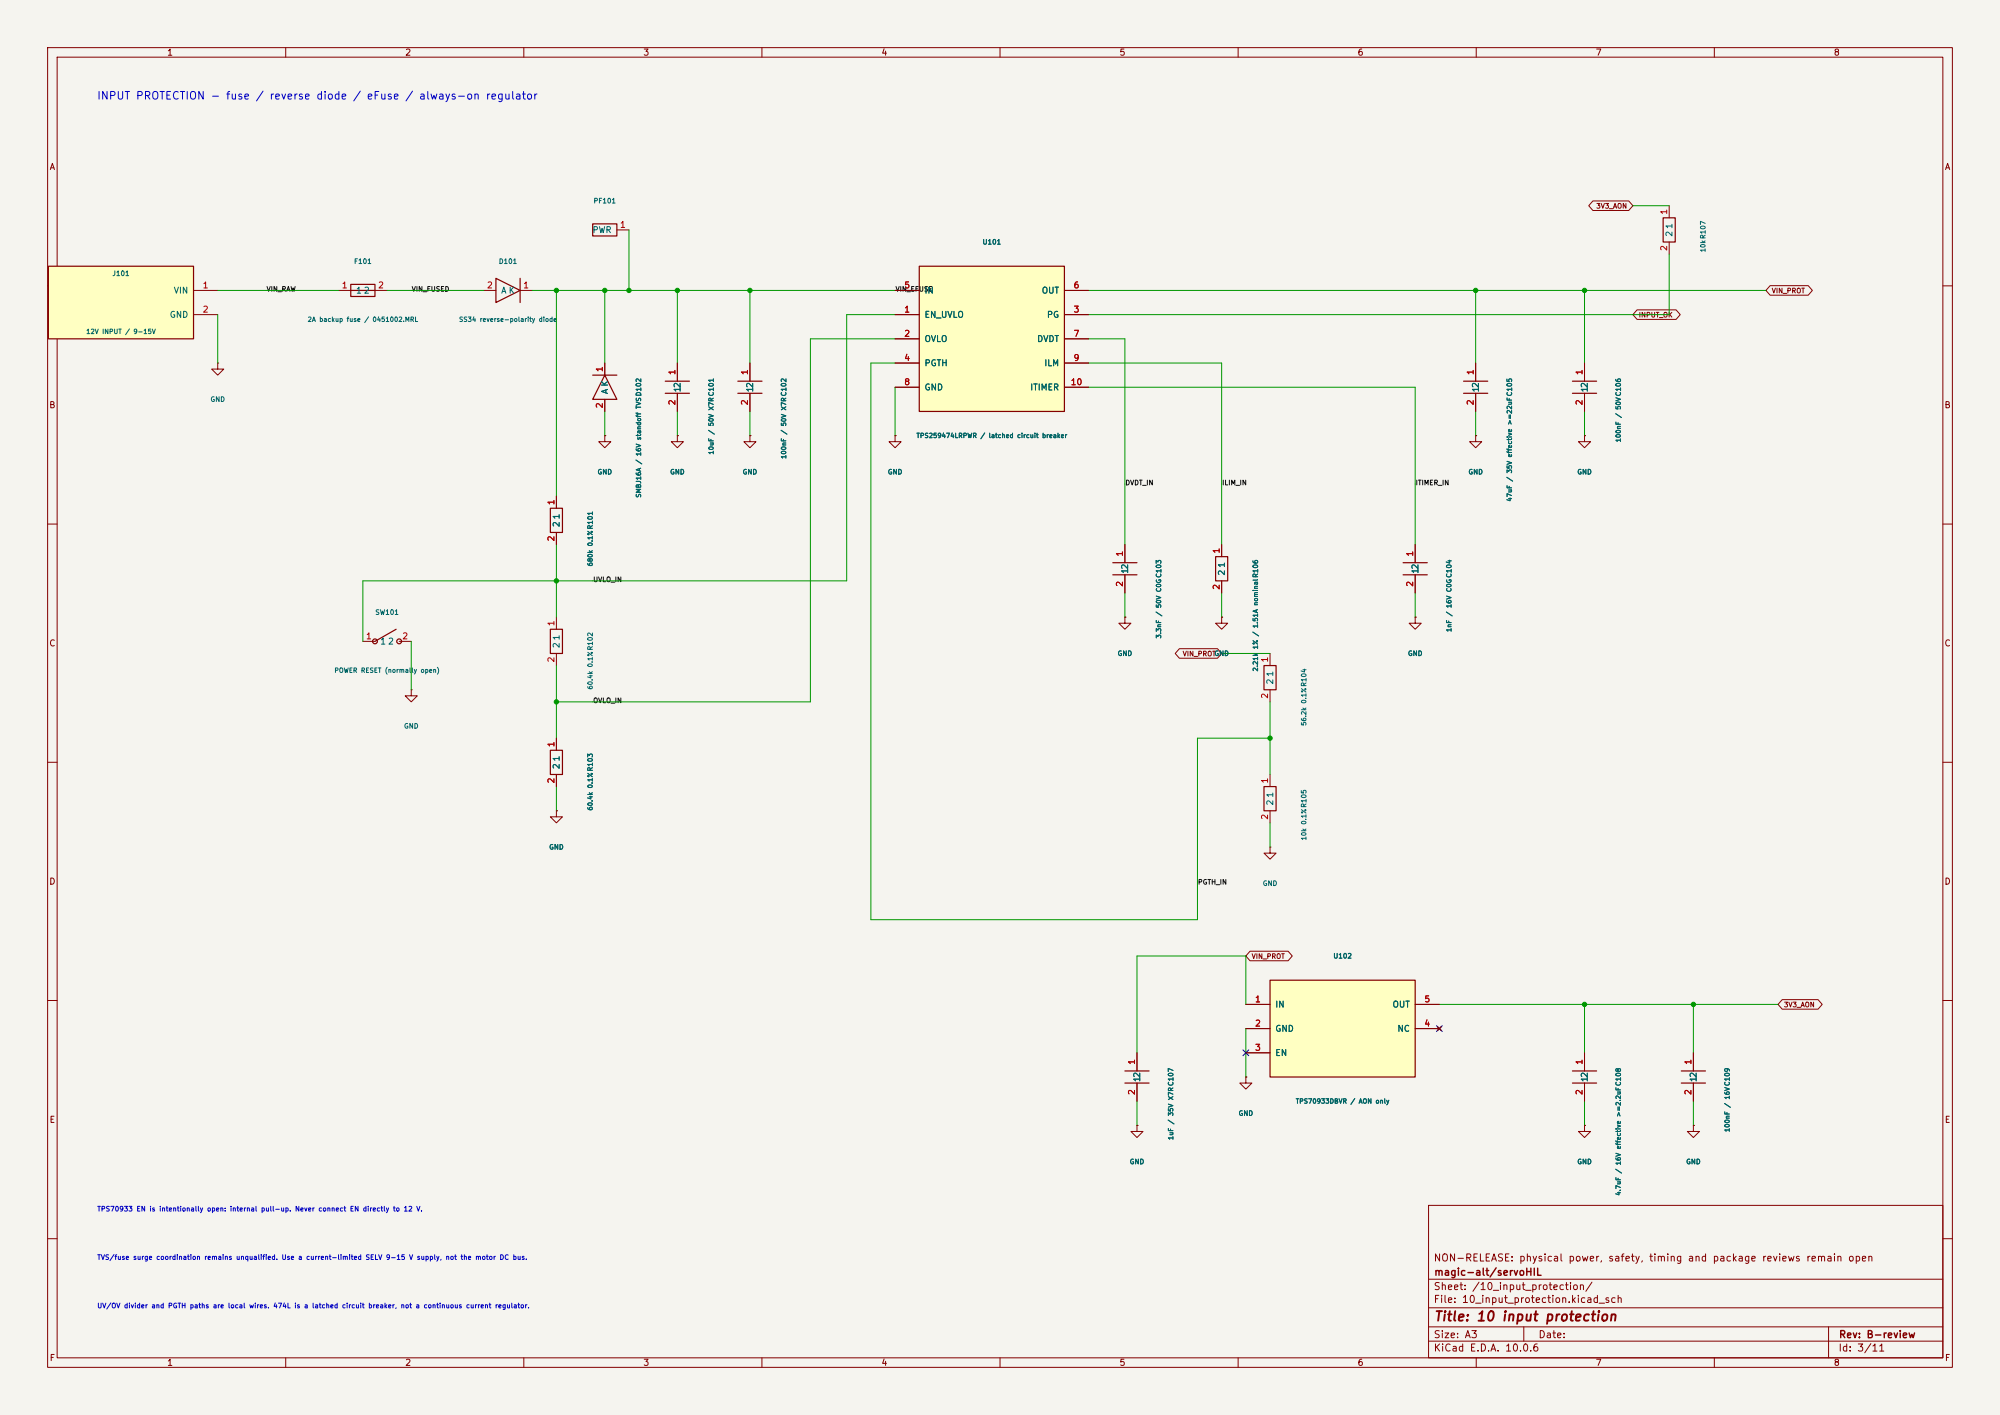
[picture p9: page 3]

INPUT PROTECTION - fuse / reverse diode / eFuse / always-on regulator

NON-RELEASE: physical power, safety, timing and package reviews remain open
magic-alt/servoHIL
Sheet: /10_input_protection/
File: 10_input_protection.kicad_sch
Title: 10 input protection

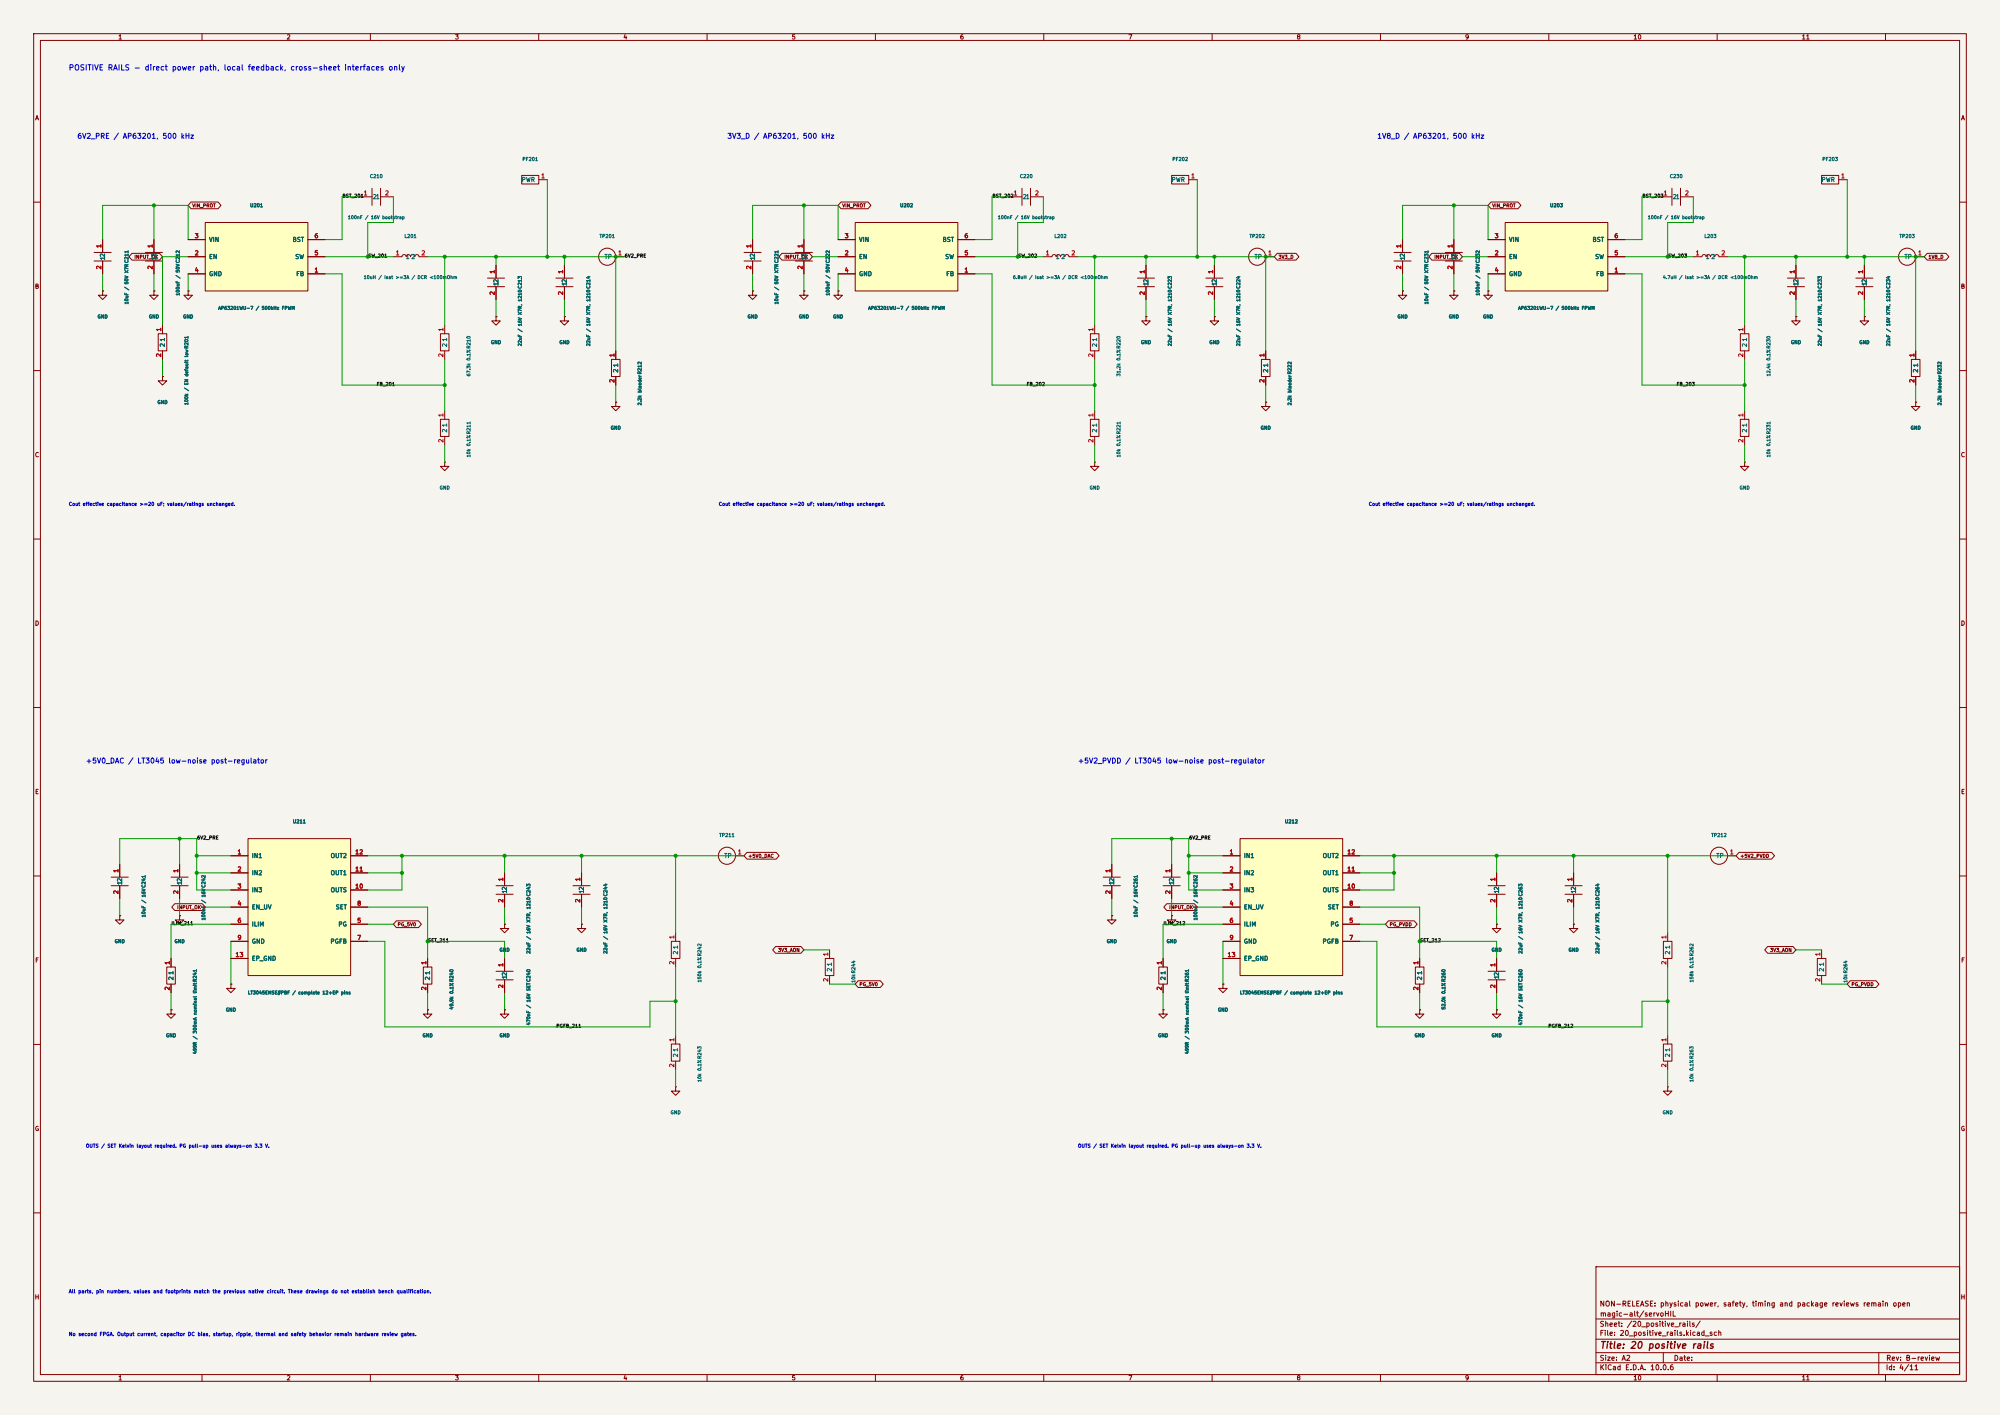
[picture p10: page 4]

POSITIVE RAILS - direct power path, local feedback, cross-sheet interfaces only

2 R201 100k / EN default low GND

GND R201 100k / EN default low 1

Cout effective capacitance >=20 uF; values/ratings unchanged.

+5V0_DAC / LT3045 low-noise post-regulator

EP_GND 13
LT3045EMSE#PBF / complete 12+EP pins GND1

LT3045EMSE#PBF / complete 12+EP pins

All parts, pin numbers, values and footprints match the previous native circuit. These drawings do not establish bench qualification. OUTS / SET Kelvin layout required. PG pull-up uses always-on 3.3 V. No second FPGA. Output current, capacitor DC bias, startup, ripple, thermal and safety behavior remain hardware review gates.

OUTS / SET Kelvin layout required. PG pull-up uses always-on 3.3 V.

NON-RELEASE: physical power, safety, timing and package reviews remain open
magic-alt/servoHIL
Sheet: /20_positive_rails/
File: 20_positive_rails.kicad_sch
Title: 20 positive rails

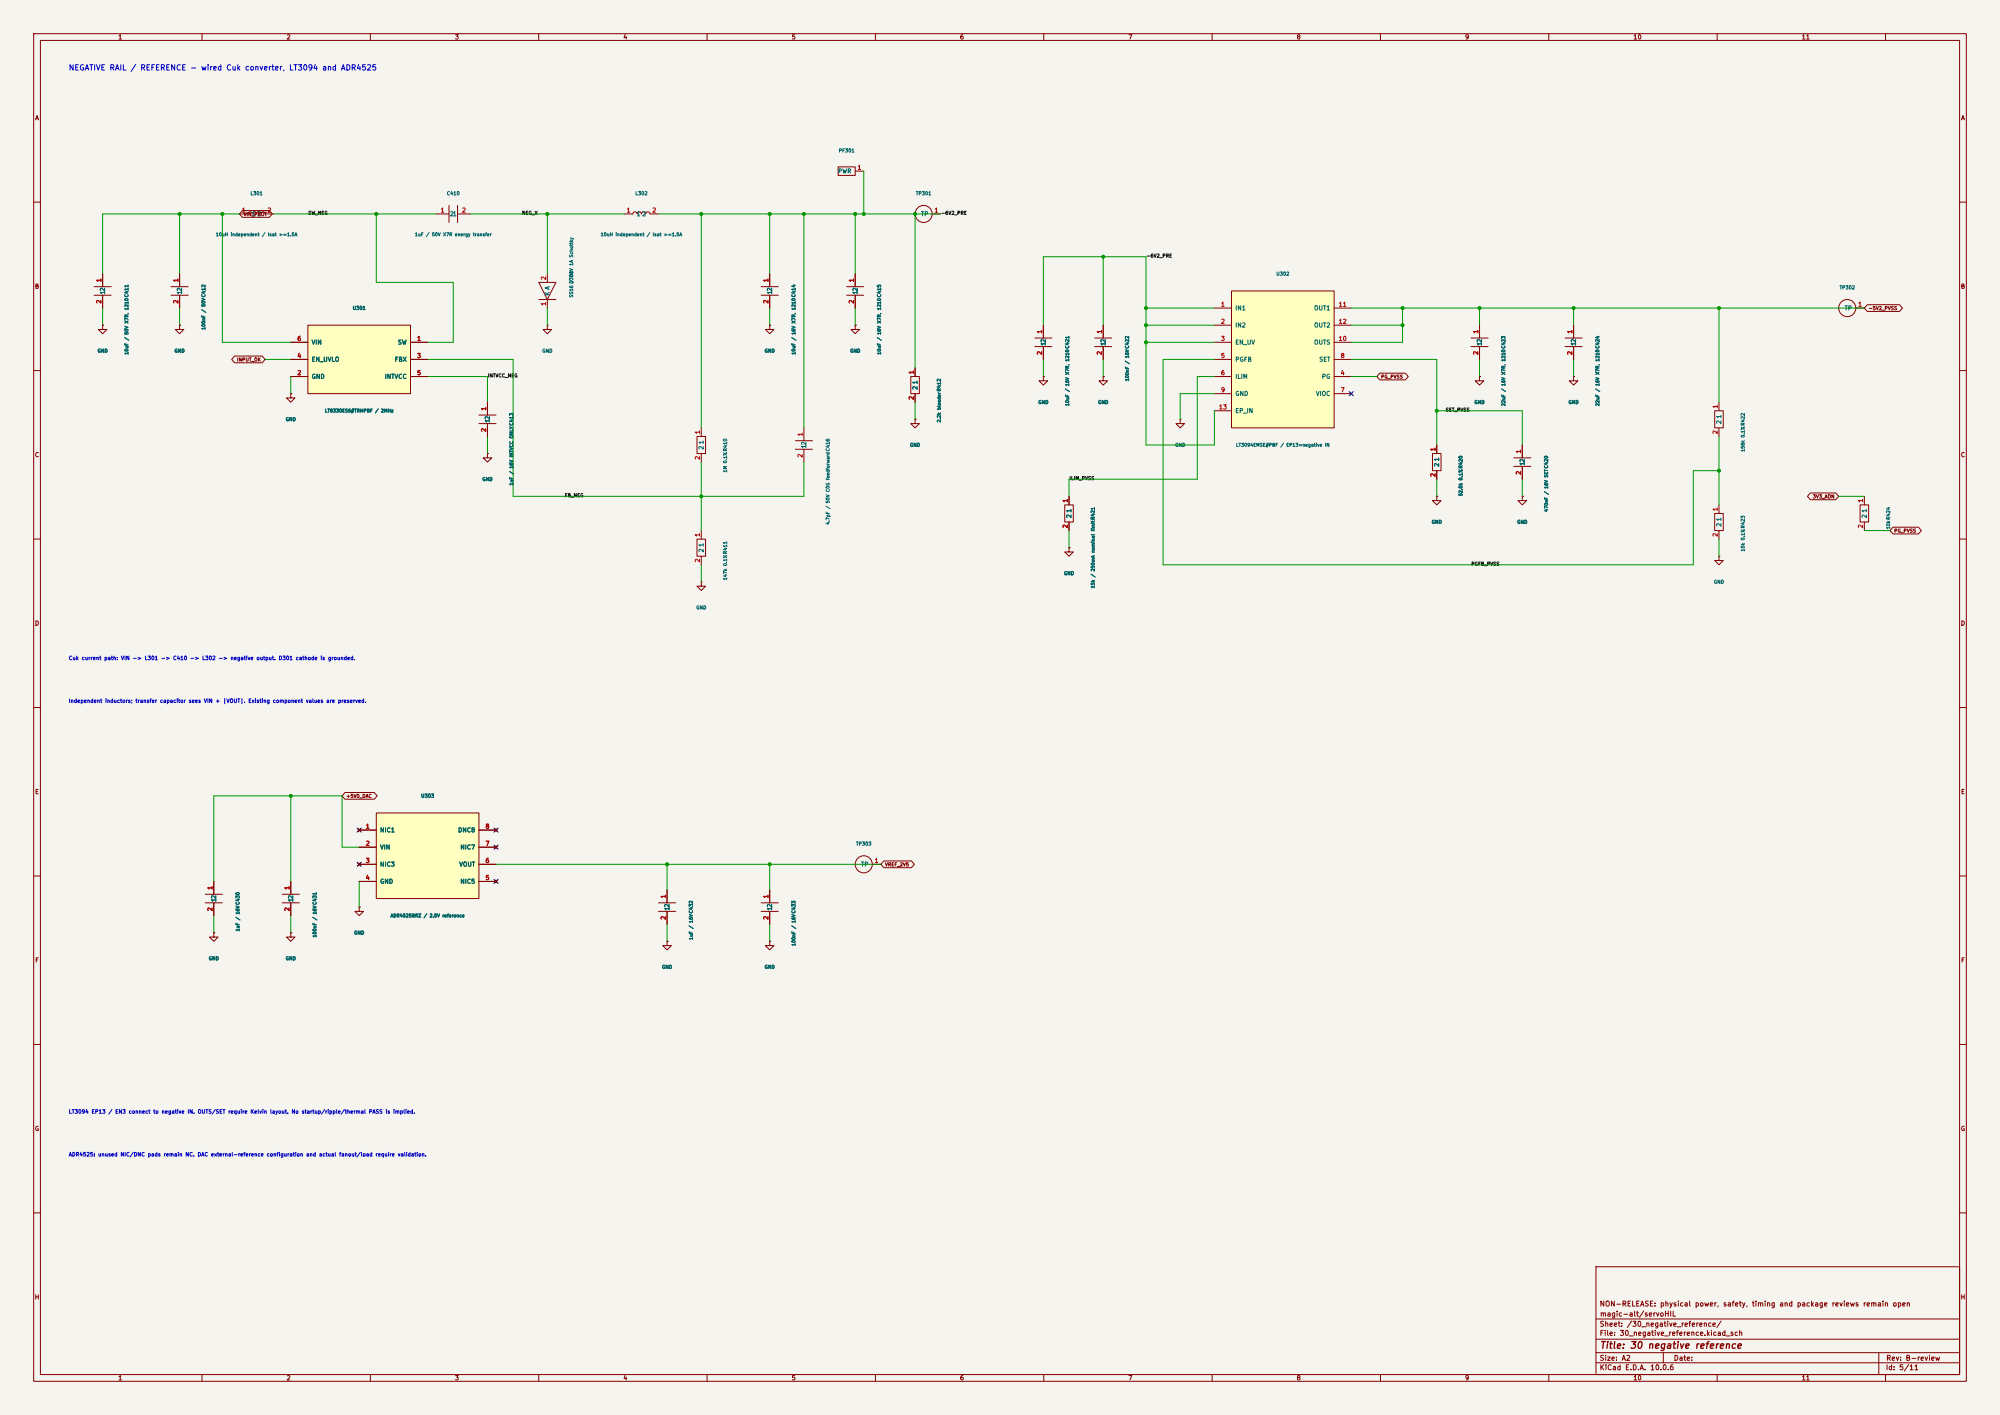
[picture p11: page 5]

NEGATIVE RAIL / REFERENCE - wired Cuk converter, LT3094 and ADR4525

2 C420 470nF / 16V SET GND SW 1 GND 2

LT3094EMSE#PBF / EP13=negative IN GND 1

Independent inductors; transfer capacitor sees VIN + |VOUT|. Existing component values are preserved. Cuk current path: VIN -> L301 -> C410 -> L302 -> negative output. D301 cathode is grounded.

ADR4525: unused NIC/DNC pads remain NC. DAC external-reference configuration and actual fanout/load require validation. LT3094 EP13 / EN3 connect to negative IN. OUTS/SET require Kelvin layout. No startup/ripple/thermal PASS is implied.

NON-RELEASE: physical power, safety, timing and package reviews remain open
magic-alt/servoHIL
Sheet: /30_negative_reference/
File: 30_negative_reference.kicad_sch
Title: 30 negative reference

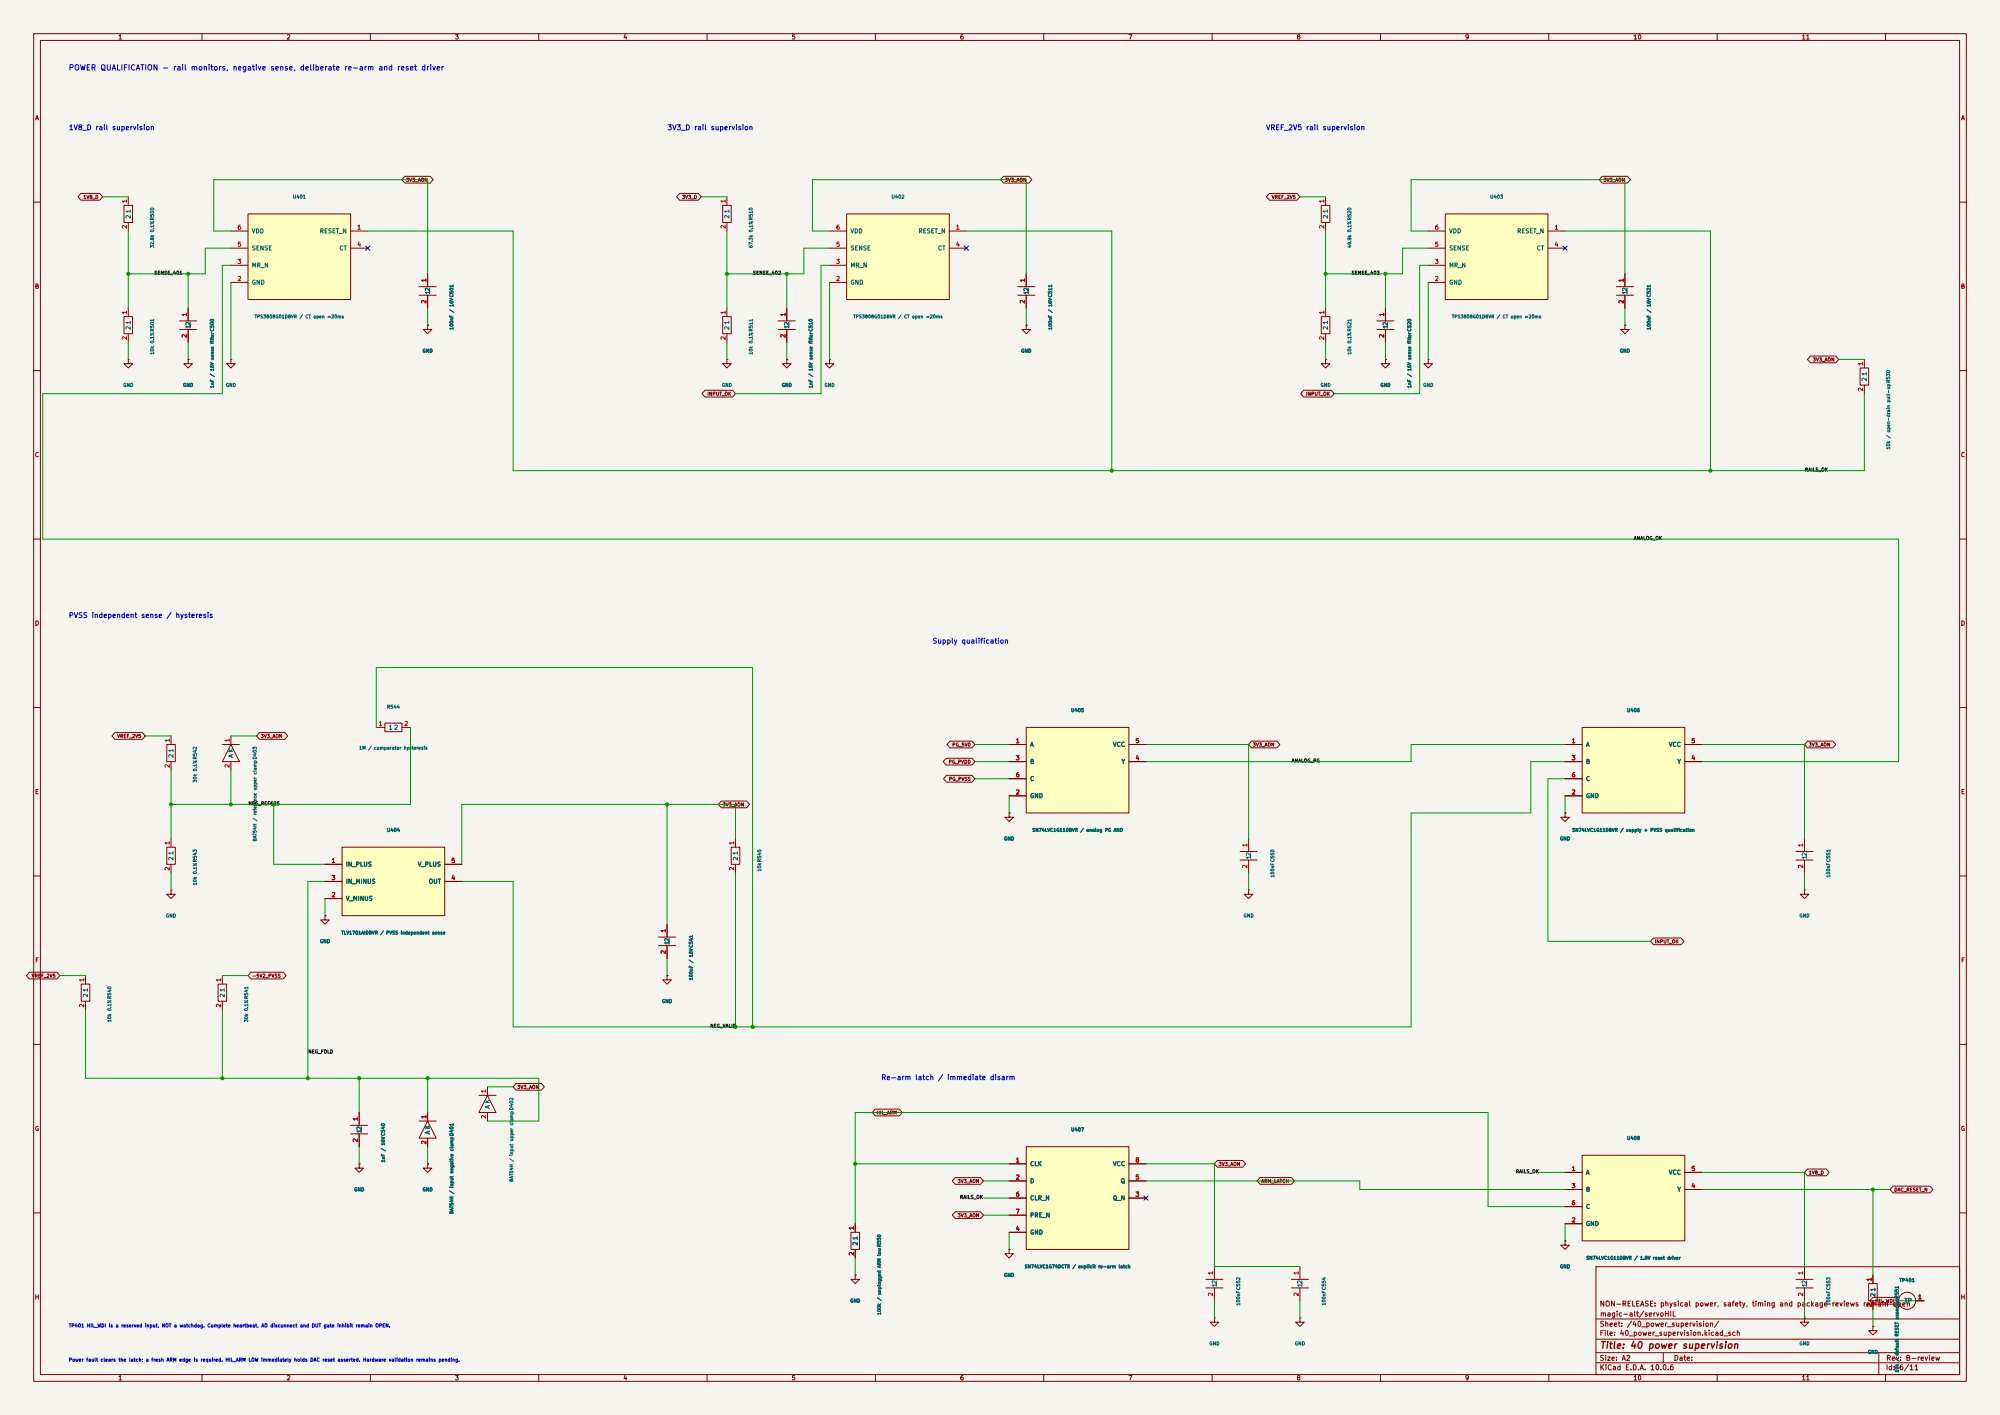
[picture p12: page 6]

POWER QUALIFICATION - rail monitors, negative sense, deliberate re-arm and reset driver

2 C510 1nF / 16V sense filter RESET_N 1 GND 2 MR_N 3 CT 4

2 C520 1nF / 16V sense filter GND GND 1

2 R530 10k / open-drain pull-up 1

PVSS independent sense / hysteresis

SN74LVC1G11DBVR / supply + PVSS qualification GND

SN74LVC1G11DBVR / analog PG AND GND

A 2 D401 BAT54H / input negative clamp GND 1

Re-arm latch / immediate disarm

2 R550 100k / unplugged ARM low GND

NON-RELEASE: physical power, safety, timing and package reviews remain open
magic-alt/servoHIL
Sheet: /40_power_supervision/
File: 40_power_supervision.kicad_sch
Title: 40 power supervision

Power fault clears the latch; a fresh ARM edge is required. HIL_ARM LOW immediately holds DAC reset asserted. Hardware validation remains pending.

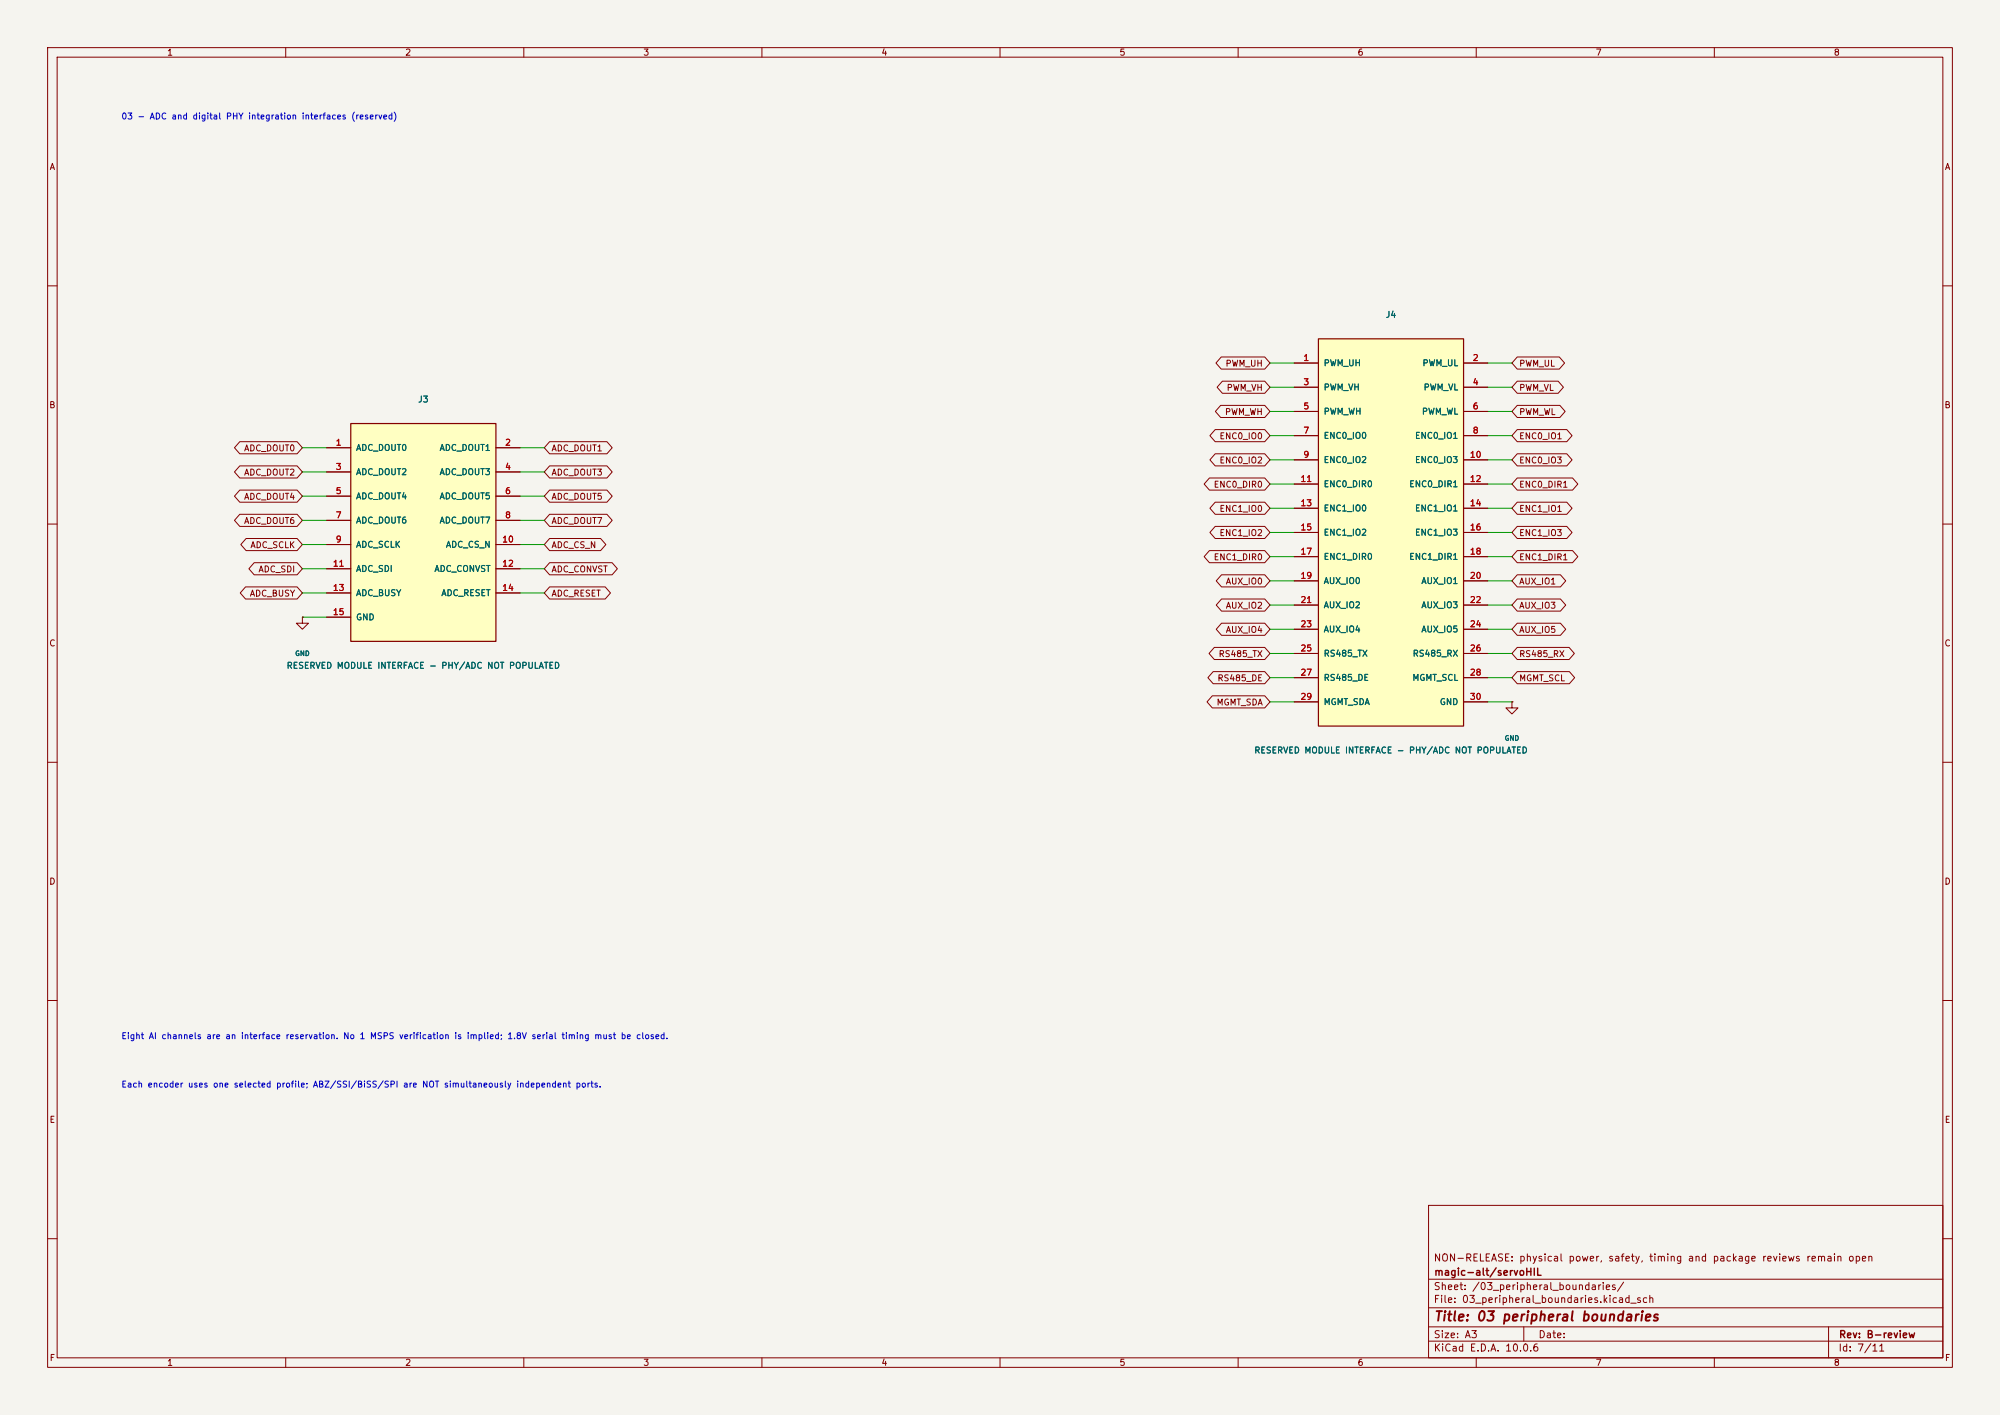
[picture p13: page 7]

03 - ADC and digital PHY integration interfaces (reserved)

J4 RESERVED MODULE INTERFACE - PHY/ADC NOT POPULATED

J3 RESERVED MODULE INTERFACE - PHY/ADC NOT POPULATED

Eight AI channels are an interface reservation. No 1 MSPS verification is implied; 1.8V serial timing must be closed. Each encoder uses one selected profile; ABZ/SSI/BiSS/SPI are NOT simultaneously independent ports.

NON-RELEASE: physical power, safety, timing and package reviews remain open
magic-alt/servoHIL
Sheet: /03_peripheral_boundaries/
File: 03_peripheral_boundaries.kicad_sch
Title: 03 peripheral boundaries

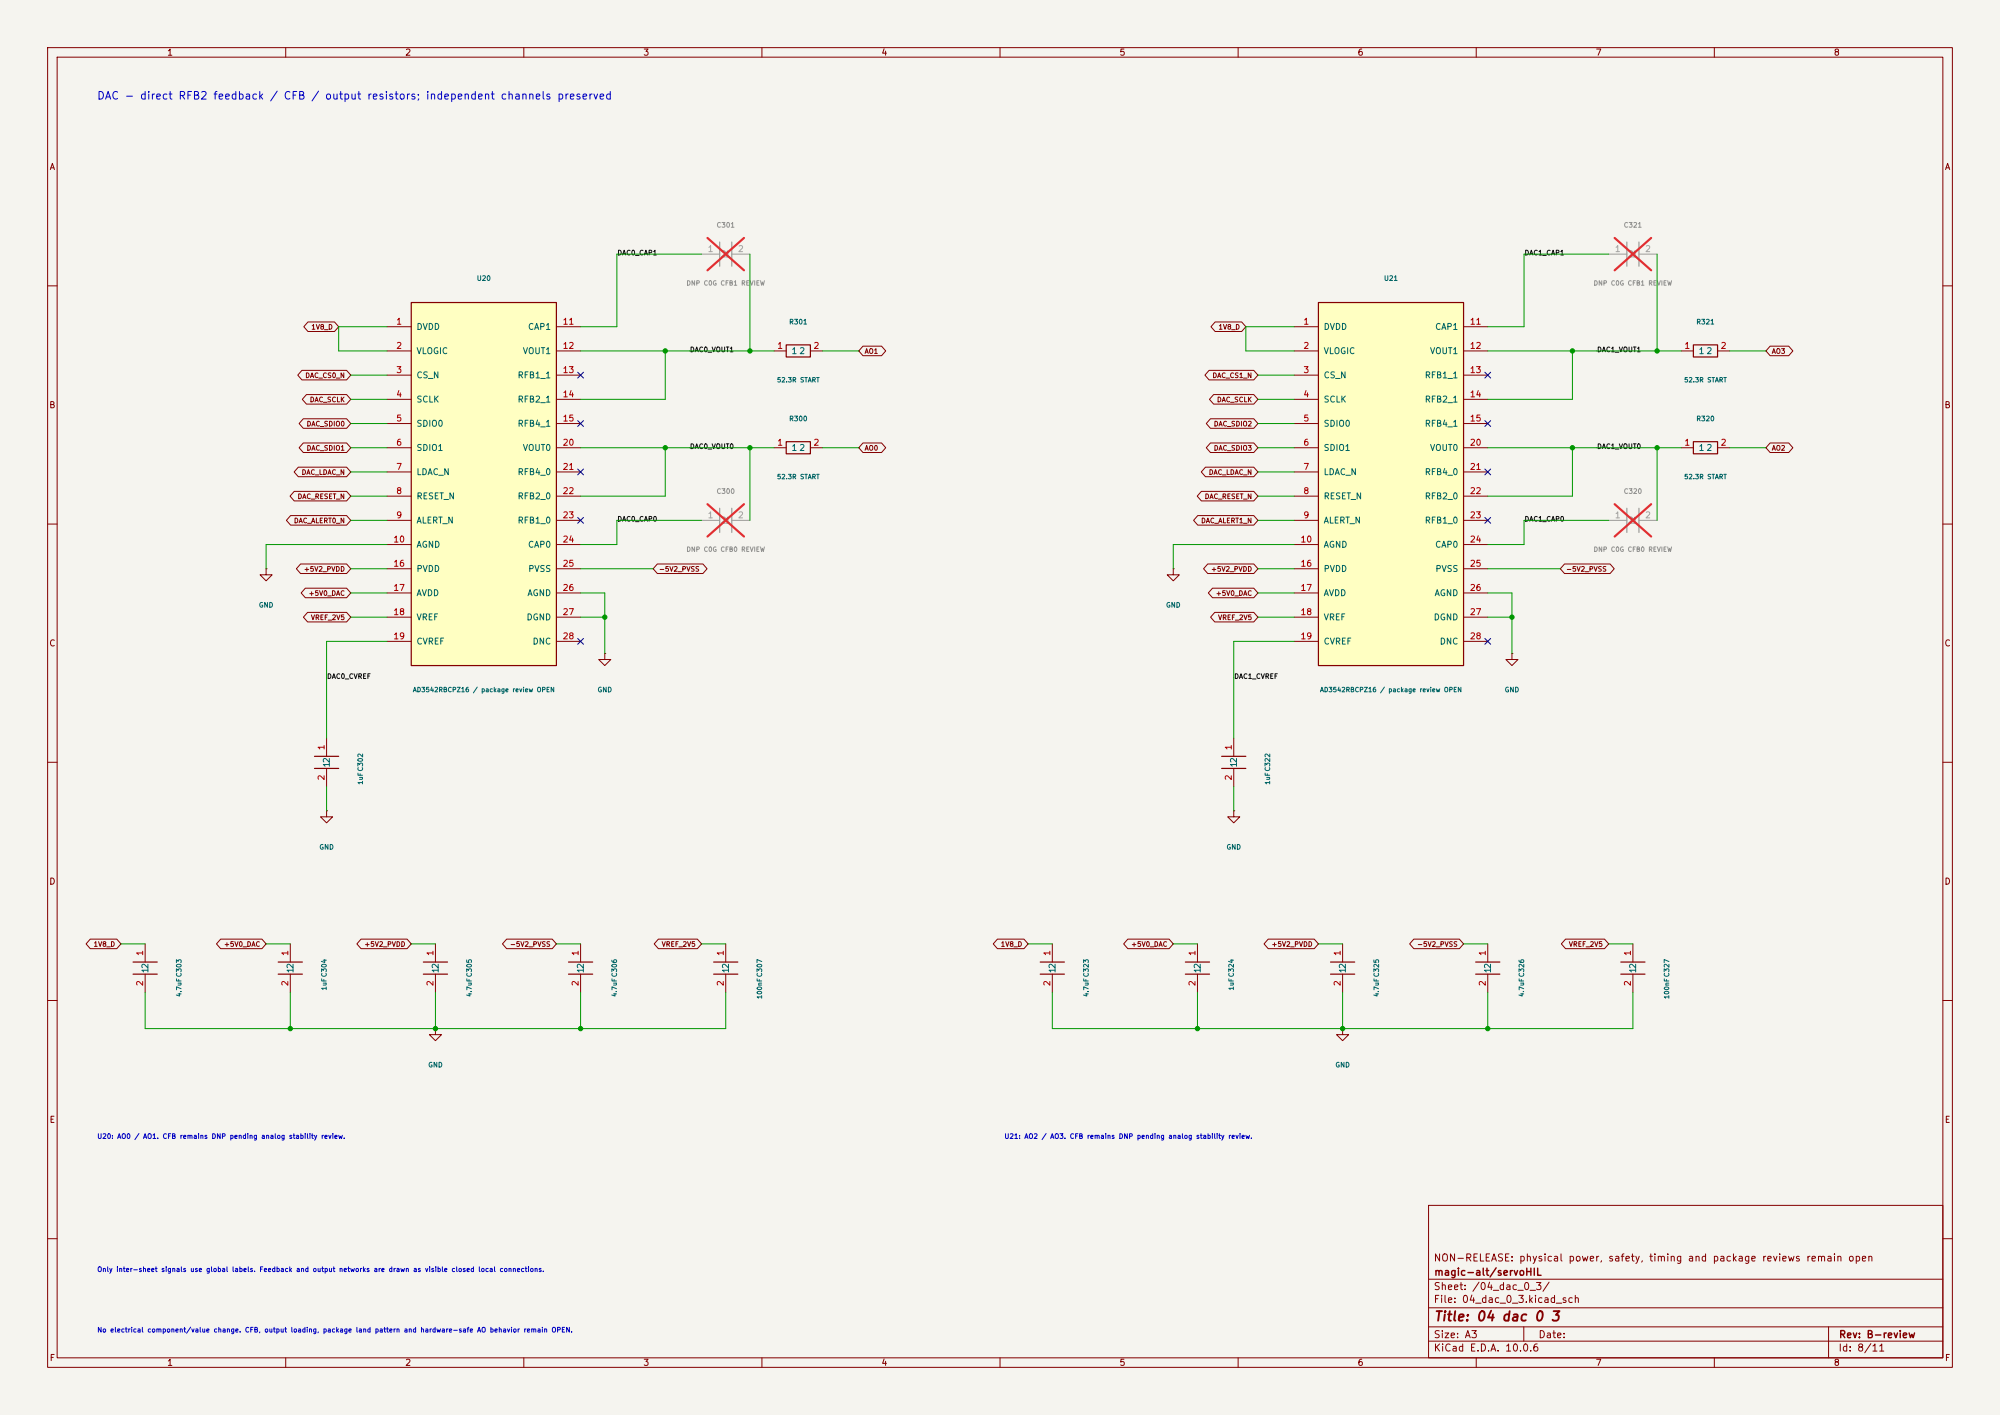
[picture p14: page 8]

DAC - direct RFB2 feedback / CFB / output resistors; independent channels preserved
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

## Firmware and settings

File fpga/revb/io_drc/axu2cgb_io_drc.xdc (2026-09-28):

# Rev.B AXU2CGB I/O-DRC harness constraint set.
# Generated as a byte-for-semantic copy of carrier.xdc.preview package-pin/IOSTANDARD assignments.
# HARNESSONLY: this file does NOT define functional clocks, I/O delays, CDC policy, or STA closure.
# It must never be used as evidence that the functional ServoHIL top has passed timing.
set_property PACKAGE_PIN F7 [get_ports {dac_sclk}]
set_property IOSTANDARD LVCMOS18 [get_ports {dac_sclk}]
set_property PACKAGE_PIN G8 [get_ports {dac_ldac_n}]
set_property IOSTANDARD LVCMOS18 [get_ports {dac_ldac_n}]
set_property PACKAGE_PIN F6 [get_ports {dac_cs0_n}]
set_property IOSTANDARD LVCMOS18 [get_ports {dac_cs0_n}]
set_property PACKAGE_PIN G6 [get_ports {dac_cs1_n}]
set_property IOSTANDARD LVCMOS18 [get_ports {dac_cs1_n}]
set_property PACKAGE_PIN D9 [get_ports {dac_cs2_n}]
set_property IOSTANDARD LVCMOS18 [get_ports {dac_cs2_n}]
set_property PACKAGE_PIN E9 [get_ports {dac_cs3_n}]
set_property IOSTANDARD LVCMOS18 [get_ports {dac_cs3_n}]
set_property PACKAGE_PIN F5 [get_ports {dac_sdio0}]
set_property IOSTANDARD LVCMOS18 [get_ports {dac_sdio0}]
set_property PACKAGE_PIN G5 [get_ports {dac_sdio1}]
set_property IOSTANDARD LVCMOS18 [get_ports {dac_sdio1}]
set_property PACKAGE_PIN E8 [get_ports {dac_sdio2}]
set_property IOSTANDARD LVCMOS18 [get_ports {dac_sdio2}]
set_property PACKAGE_PIN F8 [get_ports {dac_sdio3}]
set_property IOSTANDARD LVCMOS18 [get_ports {dac_sdio3}]
set_property PACKAGE_PIN D5 [get_ports {dac_sdio4}]
set_property IOSTANDARD LVCMOS18 [get_ports {dac_sdio4}]
set_property PACKAGE_PIN E5 [get_ports {dac_sdio5}]
set_property IOSTANDARD LVCMOS18 [get_ports {dac_sdio5}]
set_property PACKAGE_PIN C4 [get_ports {dac_sdio6}]
set_property IOSTANDARD LVCMOS18 [get_ports {dac_sdio6}]
set_property PACKAGE_PIN D4 [get_ports {dac_sdio7}]
set_property IOSTANDARD LVCMOS18 [get_ports {dac_sdio7}]
set_property PACKAGE_PIN E3 [get_ports {dac_alert0_n}]
set_property IOSTANDARD LVCMOS18 [get_ports {dac_alert0_n}]
set_property PACKAGE_PIN E4 [get_ports {dac_alert1_n}]
set_property IOSTANDARD LVCMOS18 [get_ports {dac_alert1_n}]
set_property PACKAGE_PIN F1 [get_ports {dac_alert2_n}]
set_property IOSTANDARD LVCMOS18 [get_ports {dac_alert2_n}]
set_property PACKAGE_PIN G1 [get_ports {dac_alert3_n}]
set_property IOSTANDARD LVCMOS18 [get_ports {dac_alert3_n}]
set_property PACKAGE_PIN E2 [get_ports {adc_dout0}]
set_property IOSTANDARD LVCMOS18 [get_ports {adc_dout0}]
set_property PACKAGE_PIN F2 [get_ports {adc_dout1}]
set_property IOSTANDARD LVCMOS18 [get_ports {adc_dout1}]
set_property PACKAGE_PIN D6 [get_ports {adc_dout2}]
set_property IOSTANDARD LVCMOS18 [get_ports {adc_dout2}]
set_property PACKAGE_PIN D7 [get_ports {adc_dout3}]
set_property IOSTANDARD LVCMOS18 [get_ports {adc_dout3}]
set_property PACKAGE_PIN B9 [get_ports {adc_dout4}]
set_property IOSTANDARD LVCMOS18 [get_ports {adc_dout4}]
set_property PACKAGE_PIN C9 [get_ports {adc_dout5}]
set_property IOSTANDARD LVCMOS18 [get_ports {adc_dout5}]
set_property PACKAGE_PIN A4 [get_ports {adc_dout6}]
set_property IOSTANDARD LVCMOS18 [get_ports {adc_dout6}]
set_property PACKAGE_PIN B4 [get_ports {adc_dout7}]
set_property IOSTANDARD LVCMOS18 [get_ports {adc_dout7}]
set_property PACKAGE_PIN B6 [get_ports {adc_sclk}]
set_property IOSTANDARD LVCMOS18 [get_ports {adc_sclk}]
set_property PACKAGE_PIN C6 [get_ports {adc_cs_n}]
set_property IOSTANDARD LVCMOS18 [get_ports {adc_cs_n}]
set_property PACKAGE_PIN A6 [get_ports {adc_sdi}]
set_property IOSTANDARD LVCMOS18 [get_ports {adc_sdi}]
set_property PACKAGE_PIN A7 [get_ports {adc_convst}]
set_property IOSTANDARD LVCMOS18 [get_ports {adc_convst}]
set_property PACKAGE_PIN B8 [get_ports {adc_busy}]
set_property IOSTANDARD LVCMOS18 [get_ports {adc_busy}]
set_property PACKAGE_PIN C8 [get_ports {adc_reset}]
set_property IOSTANDARD LVCMOS18 [get_ports {adc_reset}]
set_property PACKAGE_PIN A11 [get_ports {pwm_uh}]
set_property IOSTANDARD LVCMOS33 [get_ports {pwm_uh}]
set_property PACKAGE_PIN A12 [get_ports {pwm_ul}]
set_property IOSTANDARD LVCMOS33 [get_ports {pwm_ul}]
set_property PACKAGE_PIN A13 [get_ports {pwm_vh}]
set_property IOSTANDARD LVCMOS33 [get_ports {pwm_vh}]
set_property PACKAGE_PIN B13 [get_ports {pwm_vl}]
set_property IOSTANDARD LVCMOS33 [get_ports {pwm_vl}]
set_property PACKAGE_PIN A14 [get_ports {pwm_wh}]
set_property IOSTANDARD LVCMOS33 [get_ports {pwm_wh}]
set_property PACKAGE_PIN B14 [get_ports {pwm_wl}]
set_property IOSTANDARD LVCMOS33 [get_ports {pwm_wl}]
set_property PACKAGE_PIN E13 [get_ports {enc0_io0}]
set_property IOSTANDARD LVCMOS33 [get_ports {enc0_io0}]
set_property PACKAGE_PIN E14 [get_ports {enc0_io1}]
set_property IOSTANDARD LVCMOS33 [get_ports {enc0_io1}]
set_property PACKAGE_PIN A15 [get_ports {enc0_io2}]
set_property IOSTANDARD LVCMOS33 [get_ports {enc0_io2}]
set_property PACKAGE_PIN B15 [get_ports {enc0_io3}]
set_property IOSTANDARD LVCMOS33 [get_ports {enc0_io3}]
set_property PACKAGE_PIN C13 [get_ports {enc0_dir0}]
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

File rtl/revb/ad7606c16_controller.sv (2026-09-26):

`timescale 1ns/1ps
`default_nettype none
// AD7606C-16 serial software-mode controller.
// CONFIG address 0x02 uses bits[4:3]=2'b11 (0x18) for eight DOUT lanes.
// Register write: {WEN=0,R/W=0,ADDR[5:0],DATA[7:0]}.
// Register read:  {WEN=0,R/W=1,ADDR[5:0],8'h00}; the following
// all-zero 16-clock frame returns the addressed register on DOUTA and exits
// register mode. DOUT changes on SCLK rising edges; this controller samples
// on falling edges.
// This module proves digital transaction ordering only. It does NOT qualify
// ADC analog settling, calibration, anti-aliasing, board timing or 1 MSPS.
module ad7606c16_controller #(
    parameter integer SCLK_HALF_CYCLES = 5,
    parameter integer RESET_CYCLES = 10,
    parameter integer RESET_SETTLE_CYCLES = 10,
    parameter integer CONVST_CYCLES = 2,
    parameter integer BUSY_TIMEOUT_CYCLES = 10000
)(
    input  wire         clk,
    input  wire         rst_n,
    input  wire         start_init,
    input  wire         sample_request,
    input  wire         adc_busy,
    input  wire [7:0]   adc_dout,
    output reg          adc_reset,
    output reg          adc_convst,
    output reg          adc_cs_n,
    output reg          adc_sclk,
    output reg          adc_sdi,
    output reg          configured,
    output reg          sample_valid,
    output reg [127:0]  sample_words,
    output reg [31:0]   sample_seq,
    output reg [3:0]    fault_code
);
    localparam [7:0] CONFIG_VALUE = 8'h18;
    localparam [15:0] CONFIG_WRITE = {2'b00,6'h02,CONFIG_VALUE};
    localparam [15:0] CONFIG_READ  = {2'b01,6'h02,8'h00};

    localparam [3:0]
        ST_IDLE          = 4'd0,
        ST_RESET_HIGH    = 4'd1,
        ST_RESET_SETTLE  = 4'd2,
        ST_CFG_WRITE     = 4'd3,
        ST_CFG_READ_CMD  = 4'd4,
        ST_CFG_READBACK  = 4'd5,
        ST_READY         = 4'd6,
        ST_CONVST        = 4'd7,
        ST_WAIT_BUSY_HI  = 4'd8,
        ST_WAIT_BUSY_LO  = 4'd9,
        ST_SAMPLE_READ   = 4'd10,
        ST_FAULT         = 4'd11;

    localparam [3:0]
        FAULT_NONE       = 4'd0,
        FAULT_CONFIG     = 4'd1,
        FAULT_BUSY_HIGH  = 4'd2,
        FAULT_BUSY_LOW   = 4'd3;

    reg [3:0] state;
    reg [31:0] count;
    reg [31:0] half_count;
    reg [31:0] busy_count;
    reg [4:0] bit_count;
    reg [15:0] spi_tx;
    reg [15:0] reg_rx;
    reg [127:0] lane_rx;
    reg [127:0] lane_capture;
    integer lane;

`ifndef SYNTHESIS
    initial begin
        if (SCLK_HALF_CYCLES < 1 || RESET_CYCLES < 1 ||
            RESET_SETTLE_CYCLES < 1 || CONVST_CYCLES < 1 ||
            BUSY_TIMEOUT_CYCLES < 2)
            $fatal(1,"AD7606C-16 controller timing parameters invalid");
    end
`endif

    // Start a frame by assigning these registers in the caller state:
    // CS low, SCLK low, SDI=tx[15], spi_tx=tx, bit_count=0, half_count=0.
    always @(posedge clk or negedge rst_n) begin
        if (!rst_n) begin
            state <= ST_IDLE;
            count <= 0;
            half_count <= 0;
            busy_count <= 0;
            bit_count <= 0;
            spi_tx <= 0;
            reg_rx <= 0;
            lane_rx <= 0;
            lane_capture <= 0;
            adc_reset <= 0;
            adc_convst <= 0;
            adc_cs_n <= 1;
            adc_sclk <= 0;
            adc_sdi <= 0;
            configured <= 0;
            sample_valid <= 0;
            sample_words <= 0;
            sample_seq <= 0;
            fault_code <= FAULT_NONE;
        end else begin
            sample_valid <= 0;

            // Explicit initialization/recovery is authoritative and can be
            // requested from READY or FAULT; no automatic retry is performed.
            if (start_init) begin
                state <= ST_RESET_HIGH;
                count <= 0;
                half_count <= 0;
                busy_count <= 0;
                bit_count <= 0;
                adc_reset <= 1;
                adc_convst <= 0;
                adc_cs_n <= 1;
                adc_sclk <= 0;
                adc_sdi <= 0;
                configured <= 0;
                fault_code <= FAULT_NONE;
            end else begin
                case (state)
                    ST_IDLE: begin
                        adc_cs_n <= 1;
                        adc_sclk <= 0;
                        adc_sdi <= 0;
                        adc_convst <= 0;
                    end

                    ST_RESET_HIGH: begin
                        if (count >= RESET_CYCLES-1) begin
                            adc_reset <= 0;
                            count <= 0;
                            state <= ST_RESET_SETTLE;
                        end else count <= count + 1'b1;
                    end

                    ST_RESET_SETTLE: begin
                        if (count >= RESET_SETTLE_CYCLES-1) begin
                            count <= 0;
                            spi_tx <= CONFIG_WRITE;
                            bit_count <= 0;
                            half_count <= 0;
                            reg_rx <= 0;
                            adc_cs_n <= 0;
                            adc_sclk <= 0;
                            adc_sdi <= CONFIG_WRITE[15];
                            state <= ST_CFG_WRITE;
                        end else count <= count + 1'b1;
                    end

                    ST_CFG_WRITE, ST_CFG_READ_CMD, ST_CFG_READBACK, ST_SAMPLE_READ: begin
                        if (half_count >= SCLK_HALF_CYCLES-1) begin
                            half_count <= 0;
                            if (!adc_sclk) begin
                                // DOUT changes after this rising edge.
                                adc_sclk <= 1;
                            end else begin
                                // SDI is latched and DOUT is stable at this edge.
                                adc_sclk <= 0;
                                if (state == ST_CFG_READBACK)
                                    reg_rx <= {reg_rx[14:0],adc_dout[0]};
                                if (state == ST_SAMPLE_READ) begin
                                    lane_capture = lane_rx;
                                    for (lane=0; lane<8; lane=lane+1)
                                        lane_capture[16*lane +: 16] =
                                            {lane_rx[16*lane +: 15],adc_dout[lane]};
                                    lane_rx <= lane_capture;
                                end
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

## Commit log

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2026-09-23 hardware: establish ServoHIL-I/O Rev.A schematic baseline
    [01_power_entry.kicad_sch, 02_analog_power.kicad_sch, 03_digital_power.kicad_sch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]
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2026-09-23 bom: add Rev.A core component baseline
    [ServoHIL_IO_V1_RevA_Core_BOM.csv]
2026-09-23 docs: add AXU2CGB J12 HIL-Link ICD
    [ServoHIL_IO_V1_RevA_J12_HIL_Link_ICD.csv]
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2026-09-23 hardware: populate 01_power_entry Rev.A schematic
    [01_power_entry.kicad_sch]
2026-09-23 hardware: populate 02_analog_power Rev.A schematic
    [02_analog_power.kicad_sch]
2026-09-23 hardware: populate 03_digital_power Rev.A schematic
    [03_digital_power.kicad_sch]
2026-09-23 fix(power): complete LT3045/LT3094 pin contracts
    [02_analog_power.kicad_sch]
2026-09-23 fix(power): complete ADP5054 control and sequencing topology
    [03_digital_power.kicad_sch]
2026-09-23 bom: synchronize Rev.A power schematic components
    [reva-core-bom.csv]
2026-09-23 docs: synchronize Rev.A power tree with populated schematic
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2026-09-23 fix(power): rebuild digital-power sheet without generator duplication
    [03_digital_power.kicad_sch]
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2026-09-23 ci: parse Rev.A schematics with KiCad and publish ERC report
2026-09-23 ci: use KiCad stable PPA for schematic ERC support
2026-09-23 fix(erc): add explicit GND power source flag
    [01_power_entry.kicad_sch]
2026-09-23 fix(erc): declare switched preregulator rails and LT3094 parallel output
    [02_analog_power.kicad_sch]
2026-09-23 test: fail CI when KiCad ERC contains errors
2026-09-23 ci: enforce zero KiCad ERC errors
2026-09-23 style(kicad): snap 01_power_entry.kicad_sch endpoints to 50mil grid
    [01_power_entry.kicad_sch]
2026-09-23 style(kicad): snap 02_analog_power.kicad_sch endpoints to 50mil grid
    [02_analog_power.kicad_sch]
2026-09-23 style(kicad): snap 03_digital_power.kicad_sch endpoints to 50mil grid
    [03_digital_power.kicad_sch]
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2026-09-23 hardware: register standard footprints used by Rev.A power sheets
2026-09-23 fix(power): defer Rev.A power-entry footprint binding
    [01_power_entry.kicad_sch]
2026-09-23 fix(power): defer Rev.A helper footprint binding
    [03_digital_power.kicad_sch]
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2026-09-23 hardware(hil): populate AXU2CGB J12 HIL-Link schematic
    [04_axu_hil_link.kicad_sch]
2026-09-23 hardware(fpga): populate Local FPGA functional schematic
    [05_io_fpga.kicad_sch]
2026-09-23 hardware(dac): populate AD3542R AO0-AO3 schematic
    [06_dac_0_3.kicad_sch]
2026-09-23 hardware(dac): populate AD3542R AO4-AO7 schematic
    [07_dac_4_7.kicad_sch]
2026-09-23 fpga: extend Rev.A pin plan for DAC and safety interfaces
    [pin_plan.csv]
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2026-09-23 ci: validate Rev.A HIL-Link FPGA and DAC schematics
2026-09-23 fix(erc): declare FPGA rail power drivers
    [03_digital_power.kicad_sch]
2026-09-23 fix(erc): terminate unused J12 pins and snap grid
    [04_axu_hil_link.kicad_sch]
2026-09-23 fix(erc): snap Local FPGA sheet to connection grid
    [05_io_fpga.kicad_sch]
2026-09-23 fix(erc): snap AO0-AO3 sheet to connection grid
    [06_dac_0_3.kicad_sch]
2026-09-23 fix(erc): add AO DUT connector and snap grid
    [07_dac_4_7.kicad_sch]
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2026-09-23 fix(erc): use unique rail power-flag references
    [03_digital_power.kicad_sch]
2026-09-23 fix(erc): align 05_io_fpga labels to symbol pins
    [05_io_fpga.kicad_sch]
2026-09-23 fix(erc): align 06_dac_0_3 labels to symbol pins
    [06_dac_0_3.kicad_sch]
2026-09-23 fix(erc): align 07_dac_4_7 labels to symbol pins
    [07_dac_4_7.kicad_sch]
2026-09-23 hardware: mark full Rev.A schematic ERC gate passed
2026-09-23 bom: synchronize Rev.A HIL FPGA and DAC schematic
    [reva-core-bom.csv]
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2026-09-23 docs: add Rev.A HIL FPGA and DAC schematic review
2026-09-23 refactor(hardware): replace dual FPGA Rev.A with single-SoC Rev.B carrier contracts
    [01_power_entry.kicad_sch, 02_analog_power.kicad_sch, 03_digital_power.kicad_sch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]
2026-09-23 fix(schematic): keep net labels outside component bodies with explicit wires
2026-09-23 test(schematic): regress outward wire-label placement without changing pin mapping
2026-09-23 fix(schematic): fit page titles and safety pin names within drawing fields
2026-09-23 fix(revb): complete carrier-neutral generation and independent electrical checks
    [axu2cgb-carrier.csv, revb-common.csv, zu2cg-som-carrier.csv]
2026-09-23 build: prepare isolated KiCad verification tooling for native schematic work
2026-09-23 build: obtain KiCad footprint and schema assets for local schematic verification
2026-09-23 build(devtools): retain Debian KiCad runtime for offline native schematic validation
2026-09-23 fix(devtools): include KiCad kiface runtime for native schematic verification
2026-09-23 fix(revA): restore readable KiCad connectivity
    [01_power_entry.kicad_sch, 02_analog_power.kicad_sch, 03_digital_power.kicad_sch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]
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2026-09-23 fix(revA): deconflict schematic wire stubs
    [01_power_entry.kicad_sch, 02_analog_power.kicad_sch, 03_digital_power.kicad_sch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]
2026-09-23 fix(revA): orient labels away from schematic pins
    [01_power_entry.kicad_sch, 02_analog_power.kicad_sch, 03_digital_power.kicad_sch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]
2026-09-23 fix(revA): restore valid KiCad no-connect syntax
    [02_analog_power.kicad_sch, 03_digital_power.kicad_sch, 04_axu_hil_link.kicad_sch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]
2026-09-23 hardware(input): implement protected 12V and AON native schematic stage
2026-09-23 hardware(power): commit native input circuit and editable project
    [01_carrier_interface.kicad_sch, 03_peripheral_boundaries.kicad_sch, 04_dac_0_3.kicad_sch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]
2026-09-23 hardware(power): implement three FPWM bucks and positive DAC LDO section
2026-09-23 hardware(power): commit native positive circuit and editable project
    [20_positive_rails.kicad_sch, servohil_io_revB.kicad_sch]
2026-09-23 hardware(power): implement LT8330 negative supply LT3094 and precision reference
2026-09-23 fix(revA): rebalance power-entry schematic layout
    [01_power_entry.kicad_sch]
2026-09-23 fix(revA): hide noisy schematic intersheet references
2026-09-23 hardware(power): commit native negative circuit and editable project
    [30_negative_reference.kicad_sch, servohil_io_revB.kicad_sch]
2026-09-23 hardware(power): add monitored rail qualification and explicit DAC re-arm latch
2026-09-23 hardware(power): commit native supervision circuit and editable project
    [40_power_supervision.kicad_sch, servohil_io_revB.kicad_sch]
2026-09-23 fix(power): verify disarm and repair native ERC without hiding violations
    [test_native_power_netlist.py]
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2026-09-23 fix(revA): wire complete input eFuse circuit and restore detached pins
    [01_power_entry.kicad_sch]
2026-09-23 fix(revA): wire analog rails, LDO set networks and negative feedback locally
    [02_analog_power.kicad_sch]
2026-09-23 fix(revA): connect J12 damping resistors with continuous local wires
    [04_axu_hil_link.kicad_sch]
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2026-09-23 fix(revA): wire page 7 DAC feedback and supply networks as complete circuits
    [06_dac_0_3.kicad_sch]
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2026-09-24 ci(schematic): reproduce page-local global-label failures on native source
2026-09-24 fix(schematic): add guarded scope-only native label migration
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2026-09-24 fix(schematic): start verified page-local label scope repair
2026-09-24 fix(schematic): draw positive power stages as wired regulator circuits
2026-09-24 fix(revA): scope digital-power internal nets locally
    [03_digital_power.kicad_sch]
2026-09-24 fix(revA): scope FPGA-local nets to the IO sheet
    [05_io_fpga.kicad_sch]
2026-09-24 fix(revA): scope DAC4-7 local feedback and output nets
    [07_dac_4_7.kicad_sch]
2026-09-24 fix(revA): keep one analog-power global entry per rail
    [02_analog_power.kicad_sch]
2026-09-24 fix(revA): keep shared DAC0-3 rails global only once
    [06_dac_0_3.kicad_sch]
2026-09-24 ci(schematic): commit each verified repair stage and retain failed-candidate diagnostics
2026-09-24 fix(schematic): apply inherited disarm repair then page-local label migration
2026-09-24 fix(schematic): define direct input, inverting supply and DAC feedback wiring
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2026-09-24 fix(schematic): execute guarded native power and DAC redraw stages
2026-09-24 fix(schematic): execute safety, local-scope and power/DAC wiring stages with per-stage commits
2026-09-24 fix(schematic): verified repair native circuit and label repair
    [10_input_protection.kicad_sch, 20_positive_rails.kicad_sch, 30_negative_reference.kicad_sch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]
2026-09-24 fix(schematic): use local-only internal nets and standard ground symbols without mixed-scope ERC warnings
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2026-09-24 fix(schematic): preserve true cross-sheet scope and redraw local electrical circuits
2026-09-24 fix(schematic): verified scope native circuit and label repair
    [01_carrier_interface.kicad_sch, 03_peripheral_boundaries.kicad_sch, 04_dac_0_3.kicad_sch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]
2026-09-24 fix(schematic): normalize wire overlaps and trim pinless drawing tails before ERC
2026-09-24 fix(schematic): normalize explicit same-net wire geometry without moving electrical terminals
2026-09-24 ci(schematic): verify each redraw against corrected native baseline and expose precise ERC locations
2026-09-24 fix(schematic): continue verified power, DAC and supervision redraw after scope repair
2026-09-24 fix(schematic): verified positive native wiring and label repair
    [20_positive_rails.kicad_sch]
2026-09-24 fix(schematic): verified input native wiring and label repair
    [10_input_protection.kicad_sch]
2026-09-24 fix(schematic): verified negative native wiring and label repair
    [30_negative_reference.kicad_sch]
2026-09-24 fix(schematic): verified dac native wiring and label repair
    [04_dac_0_3.kicad_sch, 05_dac_4_7.kicad_sch]
2026-09-24 fix(schematic): verified supervision native wiring and label repair
    [40_power_supervision.kicad_sch]
2026-09-24 fix(schematic): verified status native wiring and label repair
    [41_power_status.kicad_sch]
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2026-09-24 fix(schematic): keep displayed values as live native properties and clear lower frame margins
2026-09-24 ci(schematic): verify live native fields and emit review previews before the final source commit
2026-09-24 fix(schematic): finalize editable Value properties and note margins
2026-09-24 fix(schematic): preserve live value editing and finish native drawing margins
    [04_dac_0_3.kicad_sch, 05_dac_4_7.kicad_sch, 10_input_protection.kicad_sch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]
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2026-09-24 test(edv): guard transient endpoint and real SET/capacitor bindings
    [test_edv_native_bench.py]
2026-09-24 fix(edv): correct native SET bindings and sample shutdown inside transient interval
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2026-09-24 fix(edv): give PWM exact solver breakpoints and verify actual duty numerically
2026-09-24 test(edv): cover real PWM convergence and fail-closed simulation evidence
    [test_edv_execution.py]
2026-09-24 fix(edv): resolve PWM edges and persist fresh fail-closed simulation manifests
2026-09-24 fix(edv): bind all capacitor banks and expose Cuk mode and thermal corner limits
    [test_edv_corners.py]
2026-09-24 fix(revA): wire local digital-power subcircuits
    [03_digital_power.kicad_sch]
2026-09-24 fix(revA): wire DAC2/DAC3 local feedback networks
    [07_dac_4_7.kicad_sch]
2026-09-24 fix(revA): make FPGA safety chain visually continuous
    [05_io_fpga.kicad_sch]
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2026-09-24 fix(revA): restore visible native wire strokes without changing connectivity
    [01_power_entry.kicad_sch, 02_analog_power.kicad_sch, 03_digital_power.kicad_sch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]
2026-09-24 test(revA): detect split and shorted native pin groups independently of labels
2026-09-24 chore(revA): apply reviewed digital-power connectivity correction
2026-09-24 fix(revA): reconnect thirteen digital-power feedback and output nodes
    [03_digital_power.kicad_sch]
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2026-09-24 fix(revA): wire U22/U23 feedback outputs and match the reviewed DAC layout
    [07_dac_4_7.kicad_sch]
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2026-09-24 test(revA): verify Cartesian pin transforms and prohibit geometric net shorts
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2026-09-24 fix(revA): gate native wire vertices and refine component field spacing
2026-09-24 fix(revA): draw continuous sequencer buck feedback and compensation circuits
    [03_digital_power.kicad_sch]
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2026-09-24 fix(revA): phase 1 replace digital power globals with explicit hierarchy
    [01_power_entry.kicad_sch, 02_analog_power.kicad_sch, 03_digital_power.kicad_sch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]
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2026-09-24 fix(revA): phase 2 wire FPGA peripherals and replace all global interfaces
    [02_analog_power.kicad_sch, 04_axu_hil_link.kicad_sch, 05_io_fpga.kicad_sch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]
2026-09-24 test(revA): catch root wire tails library drift and border collisions
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2026-09-24 test(revA): freeze original ground pin semantics instead of changing ERC pin types
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2026-09-24 fix(revA): retain original ground pin semantics while completing native review
2026-09-24 fix(revA): phase 3 reconcile symbol libraries and clear native ERC drawing warnings
    [01_power_entry.kicad_sch, 02_analog_power.kicad_sch, 03_digital_power.kicad_sch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]
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2026-09-24 test(revb): model watchdog windows and fail-closed rearm sequencing
    [test_safety_logic.py]
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2026-09-24 fix(revb): repair native negative-rail semantics and bundled footprint links
2026-09-24 feat(revb): commit ERC-clean native watchdog, eight AO switches and DUT permit
    [06_analog_outputs.kicad_sch, 40_power_supervision.kicad_sch, 50_watchdog_interlock.kicad_sch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]
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2026-09-24 build(revb): prepare native ADC and directional PHY with 461 independent pin assertions
2026-09-24 fix(revb): clear ADC title block and separate native device labels after PDF review
2026-09-24 feat(revb): commit verified native ADC PWM and differential PHY circuitry
    [03_peripheral_boundaries.kicad_sch, 70_adc_frontend.kicad_sch, 80_encoder_phy.kicad_sch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]
2026-09-24 feat(edv): bind ADC RC and loaded PHY screening to expanded power budgets
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2026-09-26 test(revb): define fail-closed DUT qualification contract
    [test_revb_qualification_gate.py]
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2026-09-28 fix(revB): close deterministic KiCad package assignments
    [01_carrier_interface.kicad_sch, 04_dac_0_3.kicad_sch, 05_dac_4_7.kicad_sch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]
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2026-09-28 feat(revB): add connector-side ESD protection sheet
    [90_connector_protection.kicad_sch, servohil_io_revB.kicad_sch]
2026-09-28 fix(revB): bind exact XAL5030 inductor footprint
    [20_positive_rails.kicad_sch]
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2026-09-28 fix(revB): keep connector protection local to interface sheets
    [03_peripheral_boundaries.kicad_sch, 06_analog_outputs.kicad_sch, 50_watchdog_interlock.kicad_sch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]
2026-09-28 fix(revB): allow only reviewed package-closure attribute deltas
    [04_dac_0_3.kicad_sch, 05_dac_4_7.kicad_sch]
2026-09-28 fix(revB): align SM712 oracle with package pin convention
    [native_peripheral_rules.py]
2026-09-28 fix(revB): snap protection symbols and refresh KiCad caches
    [03_peripheral_boundaries.kicad_sch, 04_dac_0_3.kicad_sch, 05_dac_4_7.kicad_sch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]
2026-09-28 fix(revB): bind XAL5050 production land pattern
    [20_positive_rails.kicad_sch, 30_negative_reference.kicad_sch]
2026-09-28 fix(revB): bind exact TPS25947 RPW land pattern
    [10_input_protection.kicad_sch]
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2026-09-28 test(revB): cover nine-blocker physical binding invariants
    [test_revb_schematic_closure.py]
2026-09-28 test(revB): keep component and low-energy evidence fail closed
    [test_revb_qualification_gate.py]
2026-09-28 docs(revB): replace stale hardware handoff with current gate sequence
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2026-09-28 test(revB): fail closed on unresolved AD3542R footprint geometry
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2026-09-28 feat(revB): bind U20 U21 to reviewed AD3542R footprint
    [04_dac_0_3.kicad_sch]
2026-09-28 feat(revB): bind U22 U23 to reviewed AD3542R footprint
    [05_dac_4_7.kicad_sch]
2026-09-28 feat(revB): resolve AD3542R footprint evidence from official Gerber
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2026-09-28 test(revB): cover resolved AD3542R land-pattern invariants
    [test_revb_schematic_closure.py]
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2026-09-28 fix(revB): bind native mechanical pinouts and cable fault semantics
    [test_revb_prelayout_contract.py]
2026-09-28 fix(revB): bind C105 native dielectric to X7R
    [10_input_protection.kicad_sch]
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2026-09-28 feat(revB): define J501 J701 cable-short architecture decisions
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2026-09-28 test(revB): audit J501 J701 cable-short decision contract
2026-09-28 test(revB): keep two-wire short semantics fail-closed
    [test_revb_prelayout_contract.py]
2026-09-29 feat(revB): bind 10_input_protection.kicad_sch layout parts
    [10_input_protection.kicad_sch]
2026-09-29 feat(revB): bind 06_analog_outputs.kicad_sch layout parts
    [06_analog_outputs.kicad_sch]
2026-09-29 feat(revB): bind 50_watchdog_interlock.kicad_sch layout parts
    [50_watchdog_interlock.kicad_sch]
2026-09-29 feat(revB): bind 60_dut_permit.kicad_sch layout parts
    [60_dut_permit.kicad_sch]
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2026-09-29 feat(revB): add exact PTS645 reset footprint
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2026-09-29 feat(revB): close all schematic layout-entry bindings
2026-09-29 feat(revB): bind mechanical connector and reset contracts for layout
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2026-09-29 test(revB): keep fabrication gates fail-closed after layout entry
    [test_revb_qualification_gate.py]
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2026-09-29 docs(revB): align common BOM with final layout parts
    [revb-common.csv]
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2026-09-29 fix(revB): keep C105 value numeric-first for EDV parsers
    [10_input_protection.kicad_sch]
2026-09-29 fix(revB): align C105 EDV candidate with exact layout footprint
2026-09-29 fix(revB): preserve C105 EDV voltage-rating value syntax
    [10_input_protection.kicad_sch]
2026-09-29 docs(revB): bind SW101 to official PTS645 datasheet
    [10_input_protection.kicad_sch]
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2026-09-29 fix(revB-pcb): align routing patterns with native net names
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2026-09-29 test(revB-pcb): add fail-closed Layout phase checker
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2026-09-29 fix(revB-pcb): accept documented host form factor in mechanical facts
2026-09-29 fix(revB-pcb): decode ALINX DXF legacy text encoding
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2026-09-29 fix(revB-pcb): close DXF pin1 geometry and repair CI contract
    [test_revb_pcb_layout_contract.py]
2026-09-29 docs(revB): add complete costed BOM and procurement audit
    [revb-costed.csv, revb-pricing-sources.csv]
2026-09-29 docs(revB): distinguish exact MPNs without live quotes
    [revb-costed.csv]
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
